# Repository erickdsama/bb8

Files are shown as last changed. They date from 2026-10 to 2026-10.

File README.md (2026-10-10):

# BB-8 con agente LLM

Un BB-8 de 30–35 cm que rueda, escucha y ve, manejado por Claude. Funciona como un
Sphero: una base de dos ruedas rueda por dentro de la esfera y un poste con imanes
sujeta la cabeza a través del casco. Claude nunca toca los motores: pide movimientos
acotados a un servidor MCP, el servicio de movimiento decide si obedece y el Arduino
frena solo si algo sale mal.

```
voz ─► Agente (Pi) ─► Claude ─► MCP bb8-motion ─► Servicio de movimiento ─► Arduino ─► motores, servo
                                     │                    ▲
                                     └─► Pi Zero (cabeza: cámara, ToF, ojo, voz)
                                          Mando Bluetooth ┘ (gana sobre el LLM)
```

**Toda la documentación está en la [wiki](wiki/Home.md).** Empieza por
[Arquitectura](wiki/Arquitectura.md) y luego sigue las partes en orden.

## El repo, parte por parte

El proyecto se construye en seis partes, en orden. Cada carpeta de `partes/` tiene
el código de esa parte y un README con qué hacer y cuándo está lista.

| Parte | Carpeta | Qué hay | Guía |
| --- | --- | --- | --- |
| 1 · Protoboard | [`partes/1-protoboard`](partes/1-protoboard) | Sketches de prueba `p1`…`p5` y el firmware completo del Arduino | [Parte 1](wiki/Parte-1-Protoboard.md) |
| 2 · Base de melamina | [`partes/2-base-melamina`](partes/2-base-melamina) | Montaje mecánico, sin código nuevo | [Parte 2](wiki/Parte-2-Base-de-melamina.md) |
| 3 · Base andando | [`partes/3-base-andando`](partes/3-base-andando) | Servicio de movimiento `bb8` (Pi) y `calibrar` | [Parte 3](wiki/Parte-3-Base-andando.md) |
| 4 · Agente controla el movimiento | [`partes/4-agente-movimiento`](partes/4-agente-movimiento) | Servidor MCP `bb8_mcp` y agente de voz `voz` | [Parte 4](wiki/Parte-4-Agente-controla-el-movimiento.md) |
| 5 · Agente controla la cabeza | [`partes/5-cabeza`](partes/5-cabeza) | Servidor de la cabeza `head` (Pi Zero 2 W) | [Parte 5](wiki/Parte-5-Agente-controla-la-cabeza.md) |
| 6 · Esfera y baterías | [`partes/6-esfera-baterias`](partes/6-esfera-baterias) | Gestor de energía `energia` (reposo y batería baja) | [Parte 6](wiki/Parte-6-Esfera-y-baterias.md) |

Además:

| Carpeta | Qué hay |
| --- | --- |
| [`cad/`](cad) | Piezas imprimibles en OpenSCAD paramétrico: esfera, base, poste y cabeza, con STL y renders |
| [`simulador/`](simulador) | Robot dummy: Arduino y cabeza simulados para correr todo en el PC sin hardware, y la prueba de punta a punta |
| [`sistema/`](sistema) | Servicios systemd, instaladores para la Pi y la Zero, ejemplo de `/etc/bb8.env` |
| [`docs/`](docs) | Documento técnico original y los artefactos (diagramas, avance, mecánica, animación) |
| [`wiki/`](wiki) | La wiki: guías por parte, arquitectura, protocolo, materiales, instalación |

## Pruébalo en tu PC en 2 minutos

Necesitas Python 3.11 o más nuevo. En Windows usa `py` en lugar de `python3`.

```bash
git clone https://github.com/erickdsama/bb8 && cd bb8
python3 -m venv .venv
source .venv/bin/activate              # Windows: .venv\Scripts\activate
pip install -r requirements.txt
pip install -e .                       # registra los paquetes de cada parte
python simulador/lanzar_dummy.py --camara sintetica
```

En otra terminal, con el venv activo: `python -m dummy.probar` recorre las ocho
herramientas MCP y los frenos de seguridad, y termina con `Todo bien`. Para hablarle
desde Claude Code: `claude mcp add --transport http bb8 http://127.0.0.1:8765/mcp`.
Dentro del repo, Claude Code ya lo encuentra por `.mcp.json`, y `CLAUDE.md` y `.claude/skills/` le explican el proyecto.
Detalles en [Simulador](wiki/Simulador.md) y [Conectar con Claude](wiki/Conectar-con-Claude.md).

## Por qué `pip install -e .`

El código de Python vive repartido en la carpeta de cada parte, pero los paquetes se
importan entre sí (`voz` usa `bb8.config`, el dummy usa `head`). `pyproject.toml`
mapea cada paquete a su carpeta, así que después de `pip install -e .` funcionan
`python -m bb8.motion_api`, `python -m bb8_mcp`, `python -m voz`, `python -m head.server`,
`python -m energia`, `python -m calibrar` y `python -m dummy.probar` desde cualquier
carpeta. `simulador/lanzar_dummy.py` funciona incluso sin ese paso.

## Estado

Partes 1–6 tienen código; el firmware compila para el Arduino Uno y todo se ha probado
contra el simulador, todavía no en el hardware real. Lo que falta está en
[Pendientes](wiki/Pendientes.md) y el avance en el
[tracker](docs/artefactos/avance-del-proyecto.html).

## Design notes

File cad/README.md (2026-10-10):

# CAD · piezas imprimibles del BB-8

Modelos paramétricos en OpenSCAD de todo lo que se imprime: la esfera en 14 gajos y 6
círculos, la base motriz, el poste con los imanes y la cabeza. Cambias un número en
`parametros.scad` y todo se recalcula (altura de las ruedas, de la plataforma, largo del
tubo, inclinación de los ball transfers…).

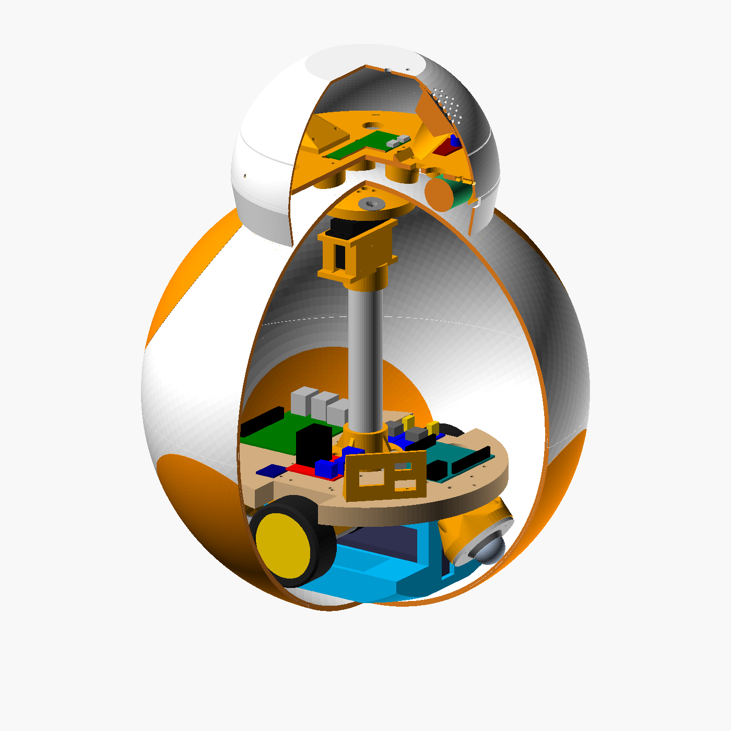
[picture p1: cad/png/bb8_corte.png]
BB-8 en corte


| Archivo | Qué tiene |
| --- | --- |
| `parametros.scad` | Todas las medidas. Las marcadas **MEDIR** vienen de hojas de vendedores que no coinciden: mide tu pieza antes de imprimir lo que depende de ellas |
| `componentes.scad` | Maquetas de lo comprado (JGB37, L298N, Uno, Pi 4, MG996R, Pi Zero, OV5647, anillo WS2812…). No se imprimen |
| `esfera.scad` | Casco: 14 gajos blancos, 6 círculos naranjas, tapa de carga, junta de bayoneta |
| `base.scad` | Plataforma (plantilla 1:1), soportes de motor, charola de LiPo con lastre, soportes de ball transfer, panel de carga |
| `poste.scad` | Pie del poste, soporte del servo, portaimanes |
| `cabeza.scad` | Casco de la cabeza, plato interior, soportes del ojo y de la bocina, tapones de las bolas |
| `ensamble.scad` | Todo junto, con corte y vista explotada |
| `exportar.sh` | Genera `stl/`, `plantillas/` y `png/` |

```bash
sudo apt install openscad xvfb      # o OpenSCAD desde openscad.org
bash cad/exportar.sh                # STL + plantilla + renders (~10 min, los gajos tardan)
bash cad/exportar.sh png            # solo los renders, segundos
openscad cad/ensamble.scad          # abrirlo y moverle
```

Los STL ya salen orientados para imprimir. Cuántas copias de cada uno, cómo imprimirlos,
la tornillería y las decisiones de diseño están en la wiki:
[Diseño 3D](../wiki/Diseno-3D.md).

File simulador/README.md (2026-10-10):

# Simulador

Robot dummy: imita al Arduino (TCP `:5555`) y a la cabeza (`:8080`) para correr el
servicio de movimiento, el MCP y el agente de voz en el PC, sin hardware.

```bash
pip install -r requirements.txt && pip install -e .     # desde la raíz del repo
python simulador/lanzar_dummy.py --camara sintetica
python -m dummy.probar                                  # en otra terminal: 19 comprobaciones
```

| Archivo | Hace |
| --- | --- |
| `lanzar_dummy.py` | Arranca dummy + `bb8.motion_api` + `bb8_mcp` |
| `dummy/world.py` | Habitación de 4 × 3 m con una silla y una caja |
| `dummy/arduino_sim.py` | Firmware simulado: protocolo, rampa, watchdog, frenos |
| `dummy/run_dummy.py` | Arduino y cabeza simulados |
| `dummy/visor.py` | Visor 2D en <http://127.0.0.1:8080/sim> |
| `dummy/probar.py` | Prueba de punta a punta por MCP |

Guía completa: [wiki/Simulador.md](../wiki/Simulador.md)

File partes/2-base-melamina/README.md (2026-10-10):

# Parte 2 · Base de melamina

Sin código nuevo: es el montaje mecánico de la base.

1. Disco de melamina 12–15 mm de Ø 20–22 cm con dos muescas para las ruedas.
2. Soportes de motor, ruedas de 65 mm con cople hexagonal de 6 mm.
3. 2 ball transfers de 1″ a 90° de las ruedas, a la misma altura de contacto.
4. Hueco de la LiPo (139 × 47 × 25 mm) centrado abajo; Arduino, L298N y buck arriba.
5. Poste central (PVC 25 mm o varilla 1/4″) con el portaimanes.
6. Repite `p2_motores_encoders` y `p4_mpu6050` de la [Parte 1](../1-protoboard): un cable flojo aparece ahí.

Piezas impresas (soportes de motor, charola con lastre, soportes de ball transfer) y la
plantilla 1:1 del disco: [`cad/`](../../cad).

**Lista cuando** se levanta con una mano y nada se mueve.

Guía completa: [wiki/Parte-2-Base-de-melamina.md](../../wiki/Parte-2-Base-de-melamina.md)

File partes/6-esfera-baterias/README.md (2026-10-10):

# Parte 6 · Esfera y baterías

El gestor de energía de la Pi principal: reposo ligero y profundo, y batería baja.

```
energia/__main__.py     máquina de estados activo → escuchando → ligero → profundo, API :8771
```

```bash
python -m energia --prueba    # tiempos cortos y sin apagar la Pi
python -m energia             # el profundo solo con BB8_REPOSO_PROFUNDO=1
```

Hardware de esta parte: LiPo 3S con fusible e interruptor, segundo buck para el
servo, Arduino alimentado por VIN, divisor de batería en A0 (`HAY_DIVISOR_BAT 1`) y
P-MOSFET de lado alto en A3 para cortar la Pi. La esfera impresa y la cabeza con
imanes también se arman aquí.

La esfera (14 gajos, 6 círculos, tapa de carga), el poste con imanes y la cabeza están
en [`cad/`](../../cad).

**Lista cuando** rueda sin cable, se duerme solo y despierta al moverlo.

Guía completa: [wiki/Parte-6-Esfera-y-baterias.md](../../wiki/Parte-6-Esfera-y-baterias.md)

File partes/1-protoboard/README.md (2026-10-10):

# Parte 1 · Componentes en protoboard

Todo lo que corre en el Arduino: cinco sketches de prueba para verificar cada
componente y el firmware completo del robot.

```
arduino/
├── pruebas/
│   ├── p1_i2c/                 ¿están vivos el MPU6050 (0x68) y el VL53L0X (0x29)?
│   ├── p2_motores_encoders/    cada motor en los dos sentidos; su encoder cuenta hacia arriba
│   ├── p3_servo/               barrido del MG996R en D9
│   ├── p4_mpu6050/             inclinación y rumbo
│   └── p5_vl53l0x/             distancia
└── bb8_firmware/               protocolo serial, PID con encoders, reflejos, reposo profundo
wokwi/                          el firmware en el simulador Wokwi (diagram.json, wokwi.toml)
```

1. Cablea según la tabla de pines de la guía (un L298N para los dos motores, jumpers ENA/ENB fuera, buck a 5.1 V en vacío).
2. Sube `p1`…`p5` en orden y abre el monitor serial a 115200 con "Nueva línea".
3. Instala la librería **VL53L0X de Pololu**, ajusta `CONFIGURACIÓN` arriba de `bb8_firmware.ino` y súbelo.
4. Desde la Pi o el PC: `python -m calibrar consola --serial /dev/ttyACM0` y prueba `I`, `?`, `M 80 80`.

Sin protoboard todavía: [wokwi/](wokwi/) corre el firmware en el simulador Wokwi con el
MPU6050, el servo, los encoders y LEDs en lugar de los motores.

**Lista cuando** `I` contesta `OK BB8 fw=0.1` y motores, servo, IMU y ToF responden.

Guía completa: [wiki/Parte-1-Protoboard.md](../../wiki/Parte-1-Protoboard.md) ·
Protocolo serial: [wiki/Protocolo.md](../../wiki/Protocolo.md)

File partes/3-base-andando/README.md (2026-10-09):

# Parte 3 · Base andando desde la Pi

El servicio de movimiento de la Pi principal y la herramienta de calibración.

```
bb8/                  paquete del servicio de movimiento
├── config.py         constantes a calibrar, límites y direcciones
├── protocol.py       líneas seriales (lo comparten la Pi y el dummy)
├── serial_link.py    una orden, una respuesta; /dev/ttyACM0 o socket://
├── motion.py         árbitro mando/LLM; move/turn con encoders y giroscopio
├── motion_api.py     API HTTP 127.0.0.1:8770
└── gamepad.py        mando Bluetooth con evdev (solo Linux)
calibrar/             consola, ticks, velocidad, rutina
```

Desde la raíz del repo, con el venv activo:

```bash
pip install -r requirements.txt evdev && pip install -e .
python -m calibrar ticks          # pulsos por vuelta (detén antes bb8.motion_api)
python -m calibrar velocidad      # ruedas en el aire
python -m bb8.motion_api --mando  # el servicio, con el mando Bluetooth
python -m calibrar rutina         # en el piso: avanza, gira 90°, vuelve
```

Copia los números a `bb8/config.py` y `PULSOS_MAX_CICLO` al firmware.

**Lista cuando** avanza, gira 90° y vuelve con deriva < 5°.

Guía completa: [wiki/Parte-3-Base-andando.md](../../wiki/Parte-3-Base-andando.md)

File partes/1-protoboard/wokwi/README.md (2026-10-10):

# Firmware en Wokwi

Simula el Arduino Uno con `bb8_firmware` en el navegador o en VS Code, antes de tener
el protoboard armado. Sirve para probar el protocolo serial y los reflejos a mano.

| Pieza real | En Wokwi | Pines |
| --- | --- | --- |
| L298N + 2 motores | 6 LEDs: `ENA`/`ENB` (brillo = PWM), `IN1`/`IN3` adelante, `IN2`/`IN4` atrás | D5 D7 D8 · D6 D11 D12 |
| Encoders de los motores | 2 perillas KY-040 (CLK = C1, DT = C2) | D2/D4 izq · D3/D10 der |
| MG996R del poste | `wokwi-servo` | D9 |
| MPU6050 | `wokwi-mpu6050` (con controles de aceleración y giro) | A4/A5, INT en A2 |
| Corte de la Pi | LED amarillo | A3 |
| Divisor de la batería | Potenciómetro (0–5 V ≈ 0–15.6 V) | A0 |
| VL53L0X | **no existe en Wokwi**: el firmware arranca sin él | — |

El anillo NeoPixel no está aquí: lo maneja la cabeza (Pi Zero), no el Arduino.

## En VS Code

1. Instala la extensión **Wokwi Simulator** (pide una licencia gratuita la primera vez).
2. Compila con los binarios exportados (los deja en `arduino/bb8_firmware/build/`, que git ignora):

   ```bash
   arduino-cli compile --fqbn arduino:avr:uno --export-binaries partes/1-protoboard/arduino/bb8_firmware
   ```

   O descarga el artefacto `firmware-uno` de la última corrida de CI y descomprímelo ahí.
3. Abre `partes/1-protoboard/wokwi/wokwi.toml` y ejecuta **Wokwi: Start Simulator**
   (si no lo encuentra, **Wokwi: Select Config File** y elige este `wokwi.toml`).

## En wokwi.com

Crea un proyecto nuevo de Arduino Uno y reemplaza sus archivos: pega
`bb8_firmware.ino` en `sketch.ino`, este `diagram.json` y este `libraries.txt`.

## Qué probar

Escribe en el monitor serial (115200, termina en salto de línea):

- `I` → `OK BB8 fw=0.1`, y `?` → la línea de estado. `F=` no debe incluir `imu`.
- `H 45` → el servo gira. `H -45` al otro lado.
- `M 120 120` → se encienden `ENA`, `ENB`, `IN1` e `IN3`, y se apagan solos a los 500 ms
  (watchdog: tecleando a mano no da tiempo de mandar otra `M`).
- Inclina el MPU6050 más de 35° (controles `accelX`/`accelY`) → `?` muestra `F=tilt` y `M` responde `ERR tilt`.
- `D 200` → hay un obstáculo a 20 cm durante 300 ms: `?` muestra `F=obstacle` y una `M` hacia
  adelante frena. Sustituye al ToF que Wokwi no tiene; como caduca rápido, pega `D 200` y `?` de una vez.
- Gira las perillas → los contadores `E=izq,der` de `?` cambian.

Ojo con el PID: los encoders no giran solos con los "motores", así que con `USAR_PID 1`
el lazo sube el PWM al máximo. Para ver el PWM directo pon `USAR_PID 0` en
`CONFIGURACIÓN`. Para probar la batería pon `HAY_DIVISOR_BAT 1` y baja el
potenciómetro: tras 5 s por debajo de ~3.2 V en A0 (9.9 V), `M` responde `ERR bateria`.

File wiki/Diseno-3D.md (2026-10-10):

# Diseño 3D

Todo lo que se imprime del BB-8, en OpenSCAD paramétrico: la esfera, la base motriz, el
poste con los imanes y la cabeza. Está en
[`cad/`](https://github.com/erickdsama/bb8/tree/main/cad); las medidas viven en
[`cad/parametros.scad`](https://github.com/erickdsama/bb8/blob/main/cad/parametros.scad)
y todo lo demás se calcula a partir de ellas.

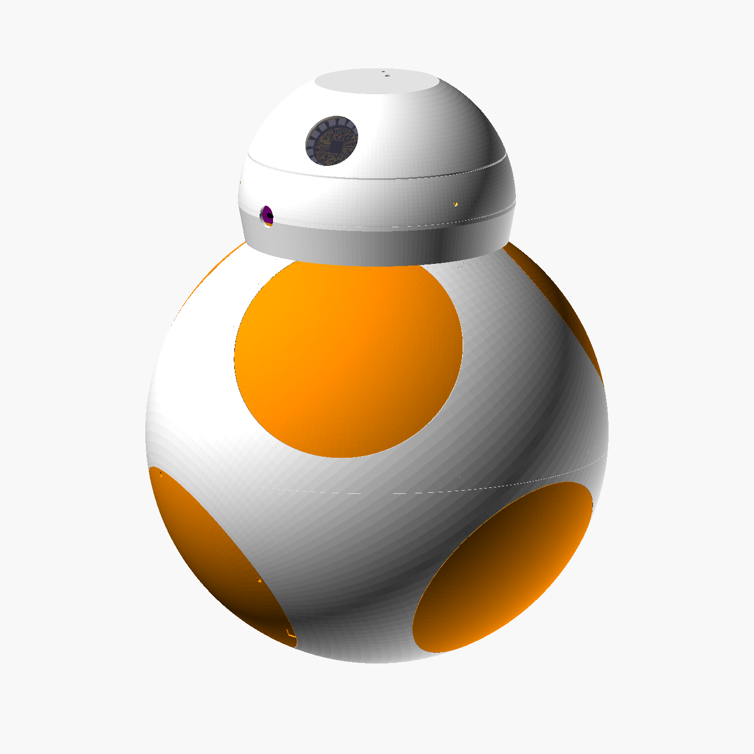
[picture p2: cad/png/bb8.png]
BB-8 completo

Corte

```bash
sudo apt install openscad xvfb
bash cad/exportar.sh          # STL en cad/stl, plantilla de la plataforma en cad/plantillas, renders en cad/png
bash cad/exportar.sh png      # solo renders
openscad cad/ensamble.scad    # el ensamble, con corte (corte=true) o explotado (explotar=1)
```

**Nada de esto se ha impreso todavía.** La geometría se revisó en el ensamble: nada de
la base, el poste ni la cabeza toca el casco salvo las ruedas y las bolas (intersección
CGAL vacía con 1 mm de margen). Antes de imprimir, mide lo marcado **MEDIR** en
`parametros.scad` (ver [Antes de imprimir](#antes-de-imprimir)).

## Cómo está pensado

Marco del robot: origen en el centro de la esfera, +z arriba, +y adelante, +x hacia la
rueda derecha. Esfera de 330 mm con pared de 4 mm (radio interior 161).

### Base

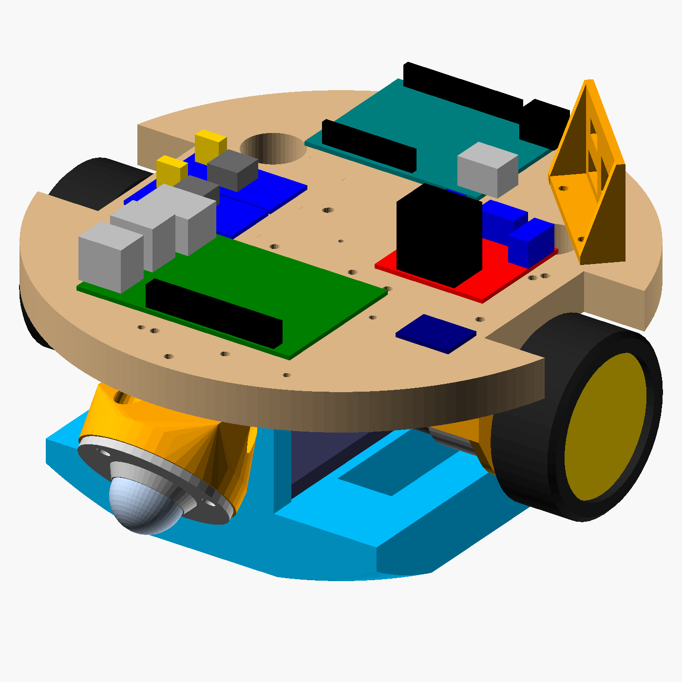
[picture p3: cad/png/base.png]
Base

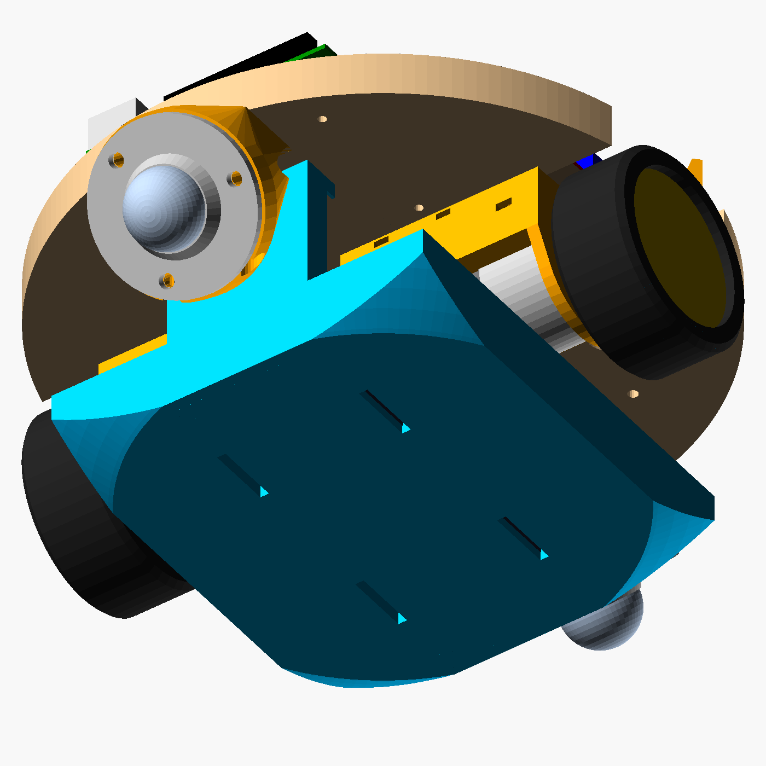
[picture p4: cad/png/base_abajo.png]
Base por abajo


- **Las ruedas salen de las piezas, no se eligen.** Los dos JGB37 van coaxiales y llenan el ancho: cople + caja de 22 mm + motor con encoder de 50 mm + 2 mm al centro ponen cada rueda a 94 mm del centro. Ahí la pared interior está inclinada 41°, así que la rueda (vertical) toca con el **borde exterior de la llanta**: fórrala con cinta de silicona y redondéale el canto. Inclinar los motores para que la llanta pise plana no cabe: el extremo del motor chocaría con el casco.
- **La plataforma va arriba y lo pesado cuelga.** El eje de las ruedas queda a z = −89.5 y la plataforma de melamina de 15 mm entre −68 y −53; a esa altura el casco deja 146 mm de radio libre, así que el disco de 210 mm entra holgado. Los motores cuelgan en soportes impresos con la placa frontal atornillada a la cara de la caja (M3 avellanados: la rueda pasa a 3 mm).
- **La LiPo va justo debajo de los motores** (z −134 a −109), en una charola colgada de la plataforma con dos paredes en los extremos. A cada lado de la LiPo, bajo los motores, hay un compartimento de lastre de 34 × 84 mm: caben ~0.5 kg de acero o ~0.75 kg de plomo por lado (la esfera recorta las esquinas), que es el lastre de 1–1.5 kg que pide la Parte 6, en el punto más bajo posible.
- **Ball transfers a ±110 mm en y**, fuera de la charola, inclinados 48° para que apunten al centro de la esfera. Sus soportes se nivelan con arandelas entre la brida y el soporte: las 4 patas (2 ruedas y 2 bolas) deben tocar el casco a la vez; si las bolas tocan primero, la esfera no rueda.
- **Plataforma:** `cad/plantillas/plataforma.svg` y `.dxf` a escala 1:1 con las muescas de las ruedas, todos los agujeros (soportes, charola, ball transfers, pie del poste, Pi 4, Uno, L298N, panel de carga) y dos pasacables de 22 mm. Imprímela en papel a 100 %, pégala en la melamina y taladra.
- Acomodo sobre la plataforma: Pi 4 adelante, Uno atrás, L298N a la izquierda, los dos LM2596 a la derecha, MPU6050 adelante a la izquierda con cinta doble cara (chip arriba) y el panel de carga atrás a la izquierda.

### Poste e imanes

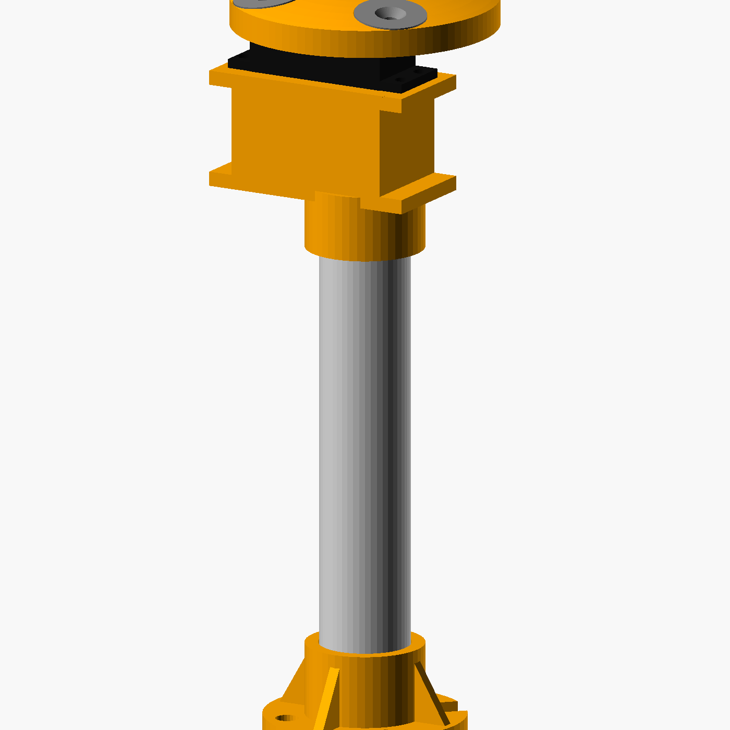
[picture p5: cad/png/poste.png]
Poste


Tubo PVC de 25 mm fijo en un pie impreso; arriba, el MG996R en un soporte que deja su eje
justo en el centro del tubo, y sobre el cuerno el portaimanes con 4 imanes N42 de 20 × 5 a
27 mm del eje. La cara de arriba del portaimanes es un casquete de la esfera interior
menos 2.5 mm: los imanes quedan a 2.5 mm del casco en toda su cara. `reportar()` en
`parametros.scad` da el largo exacto del tubo (con estas medidas, 150 mm: del fondo del pie
al tope dentro de la manga del soporte del servo). Recórtalo después de probar la base dentro de la
esfera, como pide la Parte 6.

### Cabeza

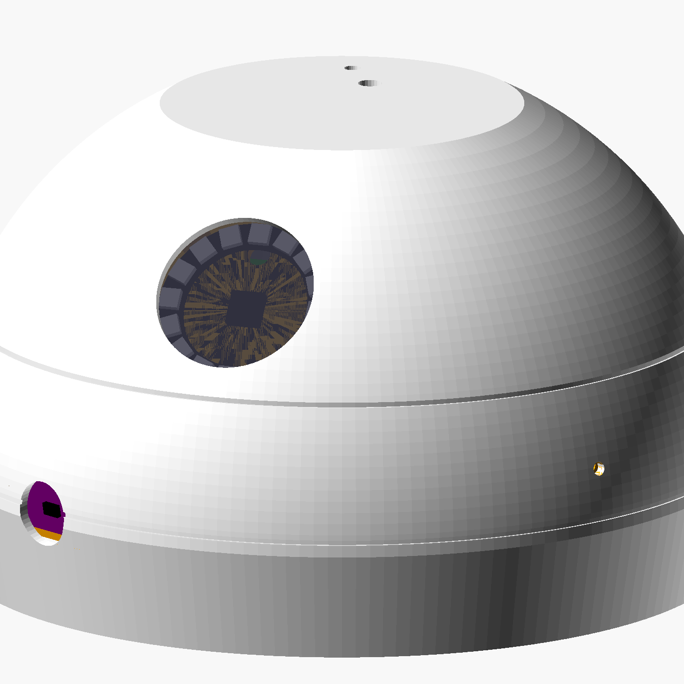
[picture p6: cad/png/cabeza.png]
Cabeza


- Ø 198 mm (0.6 de la esfera, la proporción del BB-8 de las películas), media esfera truncada arriba y una banda que baja siguiendo la curva del cuerpo a 4 mm.
- Se apoya en **3 bolas de acero de 1/2″** en copas a 60 mm del eje. Las ruedecitas del documento técnico solo ruedan en una dirección, y la esfera pasa debajo de la cabeza en todas. Las bolas entran por arriba y las retiene un tapón a presión (con grasa de litio o PTFE).
- 4 imanes en postes del plato, a 2 mm de la pintura: entre las caras de los imanes del poste y de la cabeza hay 8.5 mm (2.5 + 4 de pared + 2).
- Todo cuelga de un plato interior: el **power bank va debajo del plato**, atrás, para bajar el centro de gravedad; arriba van la Pi Zero 2 W (separadores M2.5), el PAM8403, el soporte del ojo y el de la bocina.
- **Ojo principal** a 38° de elevación: mica ahumada de 50 × 3 mm, el anillo WS2812 de 16 LED detrás y la OV5647 en un bolsillo del mismo soporte, con la lente en el centro del anillo.
- **Ojo chico** a 28° a la derecha: el VL53L0X, mirando 10° hacia abajo. Con su campo de 25°, el piso aparece hasta ~0.8 m, lejos de los 25 cm del freno.
- Bocina atrás y hacia arriba (45°) con rejilla hexagonal; dos agujeros de antena en la tapa; ranura del USB del power bank atrás, abajo.
- El casco baja sobre el plato y se fija con 3 tornillos M3 avellanados radiales a tuercas atrapadas en el plato.

### Esfera

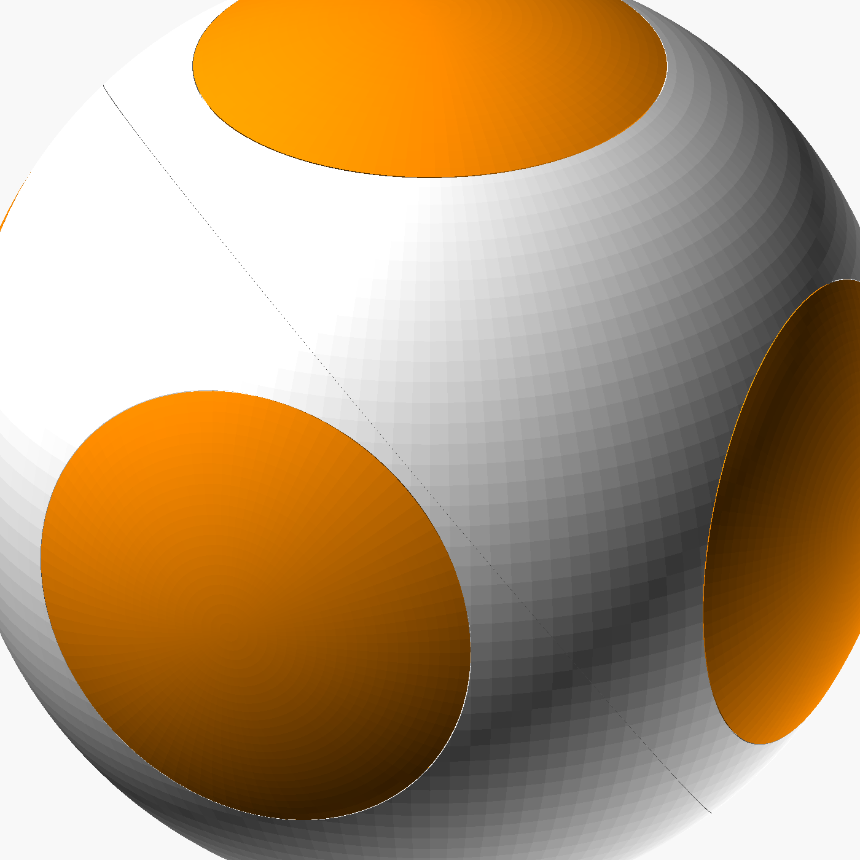
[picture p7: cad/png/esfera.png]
Esfera


- El patrón es el del BB-8: **6 círculos naranjas en las caras de un cubo** (30° de radio angular) y **8 gajos blancos**, uno por octante, como dice el documento técnico.
- **La junta de las dos mitades** es el gran círculo perpendicular a la diagonal (1,1,1) del cubo. Pasa entre los círculos a 5° de cada uno, así que ningún círculo queda partido; corta 6 gajos en dos, por eso son 14 piezas blancas.
- **Por dentro no sobresale nada**, porque ruedas y ball transfers pasan por todo el casco:
  - los círculos son tapas de 2 mm pegadas en un asiento de 2 mm (debajo queda un piso de 2 mm);
  - la junta es un traslape a media pared (10 mm) con **bayoneta de 6 lengüetas** de 0.6 mm que viven dentro de la pared: se encajan las mitades y se giran 7° para cerrar;
  - los gajos de una misma mitad se pegan a tope con espigas de filamento de 1.75 mm (18 agujeros), y luego se refuerzan por dentro con fibra de vidrio fina, lijada a ras.
- **Tapa de carga:** el círculo del eje −z del patrón tiene el piso abierto (queda una ceja de 8 mm) y se atornilla con 4 M2 × 4 avellanados. Para cargar, se gira la esfera con la mano (la base siempre cuelga) hasta ver el panel de carga por la tapa.

## Cambios respecto al documento técnico

| Documento técnico | Diseño 3D | Por qué |
| --- | --- | --- |
| XT60, JST-XH y rocker en un soporte detrás de la tapa (en el casco), con extensiones a la LiPo | Panel de carga en la **base** | La esfera gira alrededor de la base: un cable de la base al casco se enreda en la primera vuelta |
| Cabeza con 3 ruedecitas | 3 bolas de acero de 1/2″ en copas | Una rueda solo rueda en un sentido; la esfera pasa en todos |
| Cúpula de 12–14 cm | Cabeza de 198 mm (paramétrica) | El power bank mide 97 mm de largo y la proporción del BB-8 es ~0.6 del cuerpo. Cambia `cabeza_d` si prefieres otra |
| VL53L0X por I2C del Arduino | VL53L0X en la cabeza (ojo chico) | Dentro de la esfera solo vería el casco; en la cabeza lo lee la Zero (`/tof`) y el firmware va con `USAR_TOF_LOCAL 0` |
| Ball transfers "a la misma altura que las ruedas" | A ±110 mm, inclinados 48°, nivelados con arandelas | Es lo que hace que las 4 patas toquen la esfera a la vez |
| Base con LiPo "centrada abajo" | LiPo bajo los motores y lastre a sus lados en la charola | Es el punto más bajo que deja la geometría |

## Piezas a imprimir

PLA, boquilla 0.4. Los STL ya salen orientados. Cama mínima 220 × 220 × 170 mm (cada
gajo mide hasta 165 mm por lado).

| STL | Copias | Cómo |
| --- | --- | --- |
| `esfera_gajo_A_ppp` … `esfera_gajo_B_mmm` (14) | 1 de cada | 0.2 mm, 4 perímetros (pared maciza), soportes de árbol solo por dentro. El nombre dice la mitad (A/B) y el octante (p = +, m = −) |
| `esfera_circulo` | 5 | 0.2 mm, en naranja, cara convexa arriba, sin soportes |
| `esfera_tapa_carga` | 1 | Igual que los círculos |
| `base_soporte_motor`, `base_soporte_motor_izq` | 1 y 1 | 30 % de relleno, 4 perímetros |
| `base_charola` | 1 | 30 %; carga 450 g de LiPo + el lastre |
| `base_soporte_bt` | 2 | 40 %, soportes en el hueco del cuerpo |
| `base_panel_carga` | 1 | |
| `poste_pie_poste`, `poste_soporte_servo` | 1 y 1 | 30 % |
| `poste_portaimanes` | 1 | 50 %; los imanes N42 rompen piezas flojas |
| `cabeza_casco` | 1 | 0.2 mm, de pie, soportes de árbol por dentro (la tapa plana es un puente) |
| `cabeza_plato` | 1 | De cabeza (ya viene así), 30 % |
| `cabeza_soporte_ojo`, `cabeza_soporte_bocina` | 1 y 1 | Con soportes |
| `cabeza_tapon` | 3 | |

Tamaño y peso (sólido, PLA 1.24 g/cm³; es un tope, con relleno las piezas gruesas pesan menos):

| STL | Caja (mm) | cm³ | g |
| --- | --- | --- | --- |
| `base_charola.stl` | 132 × 148 × 69 | 208 | 258 |
| `base_panel_carga.stl` | 53 × 53 × 36 | 8 | 10 |
| `base_soporte_bt.stl` | 57 × 44 × 48 | 35 | 43 |
| `base_soporte_motor.stl` | 70 × 52 × 45 | 44 | 54 |
| `base_soporte_motor_izq.stl` | 70 × 52 × 45 | 44 | 54 |
| `cabeza_casco.stl` | 198 × 198 × 115 | 175 | 218 |
| `cabeza_plato.stl` | 189 × 189 × 31 | 153 | 189 |
| `cabeza_soporte_bocina.stl` | 48 × 58 × 65 | 6 | 8 |
| `cabeza_soporte_ojo.stl` | 52 × 61 × 56 | 28 | 35 |
| `cabeza_tapon.stl` | 13 × 13 × 8 | 1 | 1 |
| `esfera_circulo.stl` | 164 × 164 × 24 | 42 | 52 |
| `esfera_gajo_A_mmp.stl` | 125 × 125 × 57 | 28 | 35 |
| `esfera_gajo_A_mpm.stl` | 125 × 57 × 125 | 28 | 35 |
| `esfera_gajo_A_mpp.stl` | 140 × 163 × 163 | 112 | 138 |
| `esfera_gajo_A_pmm.stl` | 57 × 125 × 125 | 28 | 35 |
| `esfera_gajo_A_pmp.stl` | 163 × 140 × 163 | 112 | 138 |
| `esfera_gajo_A_ppm.stl` | 163 × 163 × 140 | 112 | 139 |
| `esfera_gajo_A_ppp.stl` | 163 × 163 × 163 | 133 | 165 |
| `esfera_gajo_B_mmm.stl` | 163 × 163 × 145 | 124 | 154 |
| `esfera_gajo_B_mmp.stl` | 163 × 163 × 133 | 104 | 129 |
| `esfera_gajo_B_mpm.stl` | 163 × 133 × 145 | 95 | 118 |
| `esfera_gajo_B_mpp.stl` | 49 × 115 × 115 | 21 | 26 |
| `esfera_gajo_B_pmm.stl` | 133 × 163 × 145 | 95 | 118 |
| `esfera_gajo_B_pmp.stl` | 115 × 49 × 115 | 21 | 26 |
| `esfera_gajo_B_ppm.stl` | 115 × 115 × 31 | 12 | 15 |
| `esfera_tapa_carga.stl` | 164 × 164 × 24 | 41 | 51 |
| `poste_pie_poste.stl` | 56 × 56 × 25 | 17 | 21 |
| `poste_portaimanes.stl` | 74 × 74 × 12 | 33 | 41 |
| `poste_soporte_servo.stl` | 61 × 33 × 48 | 30 | 37 |

Una copia de cada STL suma ~2.3 kg; con los 5 círculos y los 3 tapones, la esfera sola
ronda 1.6 kg de PLA, dentro de los 2–3 kg de filamento que pide la Parte 6.

## Tornillería y extras

Además del [pedido UNIT](Materiales.md):

| Pieza | Cant. | Para |
| --- | --- | --- |
| Tornillo M3 × 30 + tuerca | 18 | Soportes de motor (8), charola (4), ball transfers (6), a través de la melamina |
| Tornillo M3 × 6–8 avellanado | 6–12 | Cara de la caja de cada motor (los que coincidan de los 6) |
| Tornillo M3 × 25 + tuerca | 6 | Pie del poste (4), panel de carga (2) |
| Tornillo M4 × 16 + tuerca | 6 | Ball transfers |
| Tornillo M4 × 10 avellanado + tuerca de nylon | 8 | Imanes (ya en la lista de materiales) |
| Autorroscante M3 × 12 | 4 | Orejas del MG996R |
| Autorroscante M2 × 6 | 4 | Cuerno del servo al portaimanes |
| Autorroscante M2 × 4 avellanado | 4 | Tapa de carga |
| Tornillo M3 × 12 avellanado + tuerca | 3 | Casco de la cabeza al plato |
| Tornillo M3 × 10 + tuerca | 4 | Soportes del ojo y de la bocina |
| Separadores M2.5 de latón | 8 | Pi 4 (8 mm) y Pi Zero (5 mm) |
| Bola de acero 1/2″ (12.7 mm) | 3 | Cabeza |
| Mica acrílica ahumada Ø 50 × 3 mm | 1 | Ojo |
| Correa de velcro 20 mm | 2 | LiPo |
| Lastre (acero, plomo, perdigones con resina) | 1–1.5 kg | Charola |
| Tubo PVC conduit 25 mm | 20 cm | Poste |

**Imanes:** el poste los quiere con la **cara N avellanada** (avellanado arriba, N hacia el
casco) y la cabeza con la **cara S avellanada** (avellanado abajo). Pídelos así, o compra
8 iguales y comprueba con una brújula antes de atornillar: si la polaridad sale al revés,
la cabeza se repele.

## Antes de imprimir

Mide y corrige en `parametros.scad`:

- `caja_L` y `motor_L` del JGB37: la caja mide 19–29 mm según la reducción; el motor con encoder, ~50. Cambian la posición de las ruedas y todo lo de abajo.
- `rueda_offset`: distancia real de la cara de la caja al centro de la rueda con tu cople.
- Ball transfer: `bt_brida_d`, `bt_pcd`, `bt_cuerpo_d`, `bt_cuerpo_L`, `bt_bola_fuera`.
- MG996R: orejas (`servo_oreja_z`, `servo_agujeros`) y el cuerno (`cuerno_d`, y el radio de sus agujeros en `portaimanes`).
- `tubo_d`: el conduit de 25 mm mide 25; el hidráulico de 1/2″, 21.3.
- Cabeza: `anillo`, `tof`, `bocina_d` (la de UNIT puede ser de 40 o 50 mm), `powerbank`.
- Agujeros del L298N (`L298N_AG` en `base.scad`).

Luego imprime primero **dos gajos vecinos de mitades distintas** (por ejemplo `A_ppm` y
`B_pmm`) y prueba la bayoneta antes de gastar los 2 kg de filamento.

## Armado

1. Plataforma: corta y taladra con la plantilla. Monta motores, ruedas, charola y soportes de ball transfer; nivela con arandelas sobre una mesa (Parte 2).
2. Electrónica sobre la plataforma y prueba la base andando sin esfera (Partes 3 y 4).
3. Pega los 7 gajos de cada mitad con las espigas, refuerza por dentro y lija a ras.
4. Mete la base en la mitad B, cierra con la A y gira 7°. Prueba que rueda **antes** de poner lastre e imanes.
5. Corta el tubo, monta servo y portaimanes, pon el lastre y prueba que no vuelca al frenar.
6. Cabeza: plato con imanes, bolas y power bank; electrónica; casco con 3 tornillos.
7. Pinta: pega los círculos naranjas al final (la tapa de carga se atornilla).

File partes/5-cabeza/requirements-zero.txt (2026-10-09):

# Pi Zero 2 W (cabeza). Además: sudo apt install python3-picamera2 python3-opencv alsa-utils
# (crea el venv con --system-site-packages para ver picamera2 y opencv del sistema)
starlette>=0.37
uvicorn>=0.30
pillow>=10
adafruit-circuitpython-vl53l0x
adafruit-circuitpython-vl53l1x
adafruit-circuitpython-neopixel

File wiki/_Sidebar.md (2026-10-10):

**[Inicio](Home.md)**

**Entender**
- [Arquitectura](Arquitectura.md)
- [Protocolo](Protocolo.md)
- [Materiales](Materiales.md)

**Correr**
- [Simulador](Simulador.md)
- [Conectar con Claude](Conectar-con-Claude.md)
- [Instalación en la Pi](Instalacion-en-la-Pi.md)
- [Wake word "oye BB-8"](Wake-word-oye-BB-8.md)

**Construir**
- [1 · Protoboard](Parte-1-Protoboard.md)
- [2 · Base de melamina](Parte-2-Base-de-melamina.md)
- [3 · Base andando](Parte-3-Base-andando.md)
- [4 · Agente y movimiento](Parte-4-Agente-controla-el-movimiento.md)
- [5 · Cabeza](Parte-5-Agente-controla-la-cabeza.md)
- [6 · Esfera y baterías](Parte-6-Esfera-y-baterias.md)
- [Diseño 3D](Diseno-3D.md)

**Más**
- [Artefactos](Artefactos.md)
- [Pendientes](Pendientes.md)

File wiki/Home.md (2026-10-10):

# Wiki del BB-8

Un BB-8 de 30–35 cm que rueda, escucha y ve, manejado por Claude a través de un
servidor MCP. Esta wiki explica cómo está hecho y cómo correr cada pieza, del
protoboard a la esfera cerrada.

## Empieza aquí

1. [Arquitectura](Arquitectura.md): las tres capas (reflejos, servicio, agente), qué corre en cada placa y por qué Claude nunca toca los motores.
2. [Simulador](Simulador.md): corre todo en tu PC sin hardware y pruébalo de punta a punta.
3. [Conectar con Claude](Conectar-con-Claude.md): Claude Code, Claude Desktop o el agente de voz.

## Las seis partes, en orden

Cada parte termina con algo tangible. Nada de esfera hasta que la base ruede sola y
obedezca al agente; hasta la Parte 6 todo va con fuente de pared de 12 V.

| # | Parte | Corre en | Lista cuando |
| --- | --- | --- | --- |
| 1 | [Componentes en protoboard](Parte-1-Protoboard.md) | Arduino | Motores, servo, IMU y ToF responden; `I` contesta `OK BB8 fw=0.1` |
| 2 | [Base de melamina](Parte-2-Base-de-melamina.md) | — | Se levanta con una mano y nada se mueve |
| 3 | [Base andando desde la Pi](Parte-3-Base-andando.md) | Pi + Arduino | Avanza, gira 90° y vuelve con deriva < 5° |
| 4 | [Agente controla el movimiento](Parte-4-Agente-controla-el-movimiento.md) | Pi | "Oye Jarvis… ven acá" y se mueve |
| 5 | [Agente controla la cabeza](Parte-5-Agente-controla-la-cabeza.md) | Pi Zero + Pi | Gira la cabeza hacia ti y describe lo que ve |
| 6 | [Esfera y baterías](Parte-6-Esfera-y-baterias.md) | Pi + Arduino | Rueda sin cable, se duerme solo y despierta al moverlo |

## Referencia

- [Protocolo](Protocolo.md): serial Pi ↔ Arduino, HTTP del servicio de movimiento y de la cabeza, pinout.
- [Instalación en la Pi](Instalacion-en-la-Pi.md): servicios systemd, `/etc/bb8.env` y todas las variables `BB8_*`.
- [Wake word "oye BB-8"](Wake-word-oye-BB-8.md): entrenar el modelo propio en Colab y ponerlo en el robot.
- [Materiales](Materiales.md): lo que ya se compró (pedido UNIT 377466) y lo que falta.
- [Diseño 3D](Diseno-3D.md): esfera, base, poste y cabeza en OpenSCAD paramétrico, con STL listos para imprimir.
- [Artefactos](Artefactos.md): documento técnico, diagramas, tracker de avance, mecánica y animación.
- [Pendientes](Pendientes.md): lo que falta probar o construir.

## Mapa del repo

```
bb8/
├── partes/
│   ├── 1-protoboard/arduino/       pruebas p1…p5 + bb8_firmware
│   ├── 2-base-melamina/            montaje (sin código)
│   ├── 3-base-andando/             bb8/ (servicio de movimiento), calibrar/
│   ├── 4-agente-movimiento/        bb8_mcp/ (servidor MCP), voz/ (agente de voz)
│   ├── 5-cabeza/                   head/ (servidor de la Pi Zero)
│   └── 6-esfera-baterias/          energia/ (reposo y batería)
├── cad/                            piezas imprimibles en OpenSCAD (STL, plantilla, renders)
├── simulador/                      dummy/ + lanzar_dummy.py
├── sistema/                        systemd e instaladores
├── docs/                           documento técnico y artefactos HTML
├── wiki/                           esta wiki
├── pyproject.toml                  mapea cada paquete a su carpeta (pip install -e .)
└── requirements.txt                Pi principal y PC
```

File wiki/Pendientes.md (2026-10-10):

# Pendientes

## Probar en el hardware real

- El firmware compila para el Arduino Uno, pero solo se ha ejercitado su contraparte simulada.
- `head/backends_real.py` (cámara, ToF, NeoPixel, Piper en la Zero) no se ha corrido en la Zero.
- El agente de voz se probó contra el dummy con la API simulada, sin micrófono, Whisper ni Piper reales.
- Medir en la Pi 3 la RAM y la espera reales de Whisper `base` (hoy son estimados).

## Por construir

- Detección de obstáculos con la cámara a 5 fps en el servicio de movimiento (hoy frena el ToF).
- Entrenar el modelo "oye BB-8" en Colab (el pipeline está listo, ver [Wake word "oye BB-8"](Wake-word-oye-BB-8.md)); hasta entonces despierta con "hey Jarvis".
- Base de carga inductiva (opcional, después de la Parte 6).
- Identificación de voz sin torch (un modelo ONNX), para que quepa en la Pi 3 con Whisper local.

## Hardware confirmado

- Arduino Uno y Raspberry Pi 3 (1 GB) como Pi principal.
- La cámara OV5647 llega en otro pedido; mientras, la cabeza arranca sin ella.

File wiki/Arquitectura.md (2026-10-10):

# Arquitectura

BB-8 funciona como un Sphero: una base con dos ruedas rueda por dentro de la esfera
y la hace girar; el lastre abajo la mantiene derecha, y un poste con imanes sujeta la
cabeza a través del casco. El software no usa ROS: son tres capas, cada una más lenta
y más lista que la de abajo.

```mermaid
flowchart TD
  U[Tú, por voz] --> AG[Agente de voz<br/>Pi principal]
  AG -->|API| LLM[Claude<br/>tool use]
  LLM -->|herramientas MCP| MCP[Servidor MCP bb8-motion<br/>:8765/mcp]
  J[Mando Bluetooth<br/>gana sobre el LLM] --> MS[Servicio de movimiento<br/>127.0.0.1:8770]
  MCP --> MS
  MS -->|USB serial 115200| AR[Arduino<br/>firmware propio]
  AR --> M[2 motores + servo del poste]
  MCP <-->|WiFi :8080| Z[Pi Zero 2 W · cabeza<br/>cámara, ToF, ojo, altavoz]
  MS -->|GET /tof| Z
```

## Las tres capas

| Capa | Dónde | Ciclo | Hace |
| --- | --- | --- | --- |
| Reflejos | Arduino ([firmware](https://github.com/erickdsama/bb8/tree/main/partes/1-protoboard/arduino/bb8_firmware)) | 10 ms | Rampa, PID con encoders; frena si se inclina > 35°, si hay un obstáculo a < 25 cm o si pasan 500 ms sin órdenes |
| Servicio de movimiento | Pi, Python ([`bb8`](https://github.com/erickdsama/bb8/tree/main/partes/3-base-andando/bb8)) | 50 ms | Único dueño del serial. Convierte metros y grados en pulsos de encoder, arbitra entre mando y LLM, impone límites |
| Agente | Claude vía MCP ([`bb8_mcp`](https://github.com/erickdsama/bb8/tree/main/partes/4-agente-movimiento/bb8_mcp)) | 1–4 s | Decide qué herramienta sigue según lo que ve y oye |

Cada herramienta es corta y termina sola (máx. 2 m, 5 s, PWM 55 %), así que mientras
Claude piensa no hay un motor girando. Los límites viven en el servicio y en el
firmware, no en el prompt.

## Qué corre en cada placa

| Placa | Procesos | Código |
| --- | --- | --- |
| Raspberry Pi principal | `bb8.motion_api` (:8770), `bb8_mcp` (:8765), `voz`, `energia` (:8771) | partes 3, 4 y 6 |
| Raspberry Pi Zero 2 W (cabeza) | `head.server` (:8080): cámara OV5647, ToF, anillo WS2812, altavoz | parte 5 |
| Arduino Uno | `bb8_firmware`: L298N, encoders, servo MG996R, MPU6050, VL53L0X | parte 1 |
| Tu PC | El simulador reemplaza al Arduino y a la Zero; el resto es el mismo código | `simulador/` |

## Herramientas que ve Claude

| Herramienta | Qué hace |
| --- | --- |
| `move(metros)` | Avanza o retrocede hasta 2 m; devuelve `done`, `blocked` (obstáculo), `manual_override`, `cancelled` o `error` |
| `turn(grados)` | Gira sobre su eje con el giroscopio; + es derecha |
| `stop()` | Cancela cualquier movimiento |
| `look_at(grados)` | Gira la cabeza −90…90° con el servo del poste |
| `take_photo()` | Foto de la cabeza, 640 px |
| `set_eye_color(color, patron)` | Anillo NeoPixel |
| `say(texto o sonido)` | Habla con Piper (con balbuceo de pitidos antes) o pita |
| `express(emocion)` | Pitido de la emoción y el color de ojo que le toca (15 emociones, `head/personalidad.py`) |
| `get_pose()` | Posición, rumbo, inclinación, batería, distancia al frente |

## Seguridad

- El mando Bluetooth gana si se tocó en el último segundo.
- Voces no registradas pueden platicar, pero `move`, `turn` y `look_at` se bloquean en el código.
- El Arduino frena solo; Claude se entera después por el resultado `blocked`.
- El MCP escucha en 127.0.0.1 por defecto. Con `--host 0.0.0.0` no tiene contraseña: solo en la WiFi de casa.

Los mensajes exactos de cada enlace están en [Protocolo](Protocolo.md). Los diagramas
de cableado, alimentación y secuencia están en el artefacto
[Diagramas](Artefactos.md#diagramas).

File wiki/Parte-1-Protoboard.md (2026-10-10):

# Parte 1 · Componentes en protoboard

**Entregable:** los dos motores giran en ambos sentidos desde el Arduino con sus
encoders contando, el servo barre, la IMU y el ToF responden, y el firmware completo
contesta `OK BB8 fw=0.1`.

Código: [`partes/1-protoboard/arduino`](https://github.com/erickdsama/bb8/tree/main/partes/1-protoboard/arduino).

## Materiales

Arduino Uno, 1 L298N (el segundo queda de repuesto), 2 motorreductores
JGB37-520B 12 V 319 RPM con encoder, servo MG996R, MPU6050, VL53L0X, buck LM2596,
condensador 1000 µF 16 V, adaptador de 12 V 2 A con jack, protoboard + cables, Raspberry
Pi con su cargador. Todo viene en el [pedido UNIT 377466](Materiales.md).

## Cableado

| Pin Arduino | Va a | Uso |
| --- | --- | --- |
| D5 · D6 | L298N ENA · ENB | PWM izq · der (Timer0) |
| D7 · D8 | L298N IN1 · IN2 | Sentido motor izquierdo |
| D11 · D12 | L298N IN3 · IN4 | Sentido motor derecho |
| D2 · D4 | Encoder izq C1 · C2 | D2 = INT0 |
| D3 · D10 | Encoder der C1 · C2 | D3 = INT1 |
| D9 | Servo MG996R (naranja) | La librería Servo toma Timer1 |
| A4 · A5 | MPU6050 (0x68) + VL53L0X (0x29) | I2C SDA · SCL |
| A2 | MPU6050 INT | Despertar del reposo |
| A0 | Divisor de batería | Opcional, Parte 6 |
| A3 | MOSFET de la Pi | Parte 6, reposo profundo |
| USB | Raspberry Pi | Serial 115200 y 5 V |

- Adaptador 12 V → L298N (+12 V, GND) y → LM2596.
- LM2596 ajustado a **5.1 V sin nada conectado** → condensador 1000 µF (pata larga a +) → servo (rojo 5.1 V, café GND).
- En el L298N: quita los jumpers ENA y ENB, deja el jumper 5V-EN. No uses su salida de 5 V.
- Encoders: VCC 5 V y GND del Arduino.
- **Un solo riel de GND** para fuente, L298N, buck, servo y Arduino; la Pi llega por el USB.
- El Arduino come 5 V del USB de la Pi, así que una caída de los 12 V no lo reinicia.

Diagrama completo en el artefacto [Diagramas](Artefactos.md#diagramas), sección 1.

> Con el adaptador de 2 A no frenes una rueda con la mano mientras se mueve el servo:
> un motor trabado más el servo a tope pasan de 2 A.

## Sketches de prueba, en orden

Ábrelos en el Arduino IDE, sube, y abre el monitor serial a 115200 con "Nueva línea".
Ruedas en el aire la primera vez.

| Sketch | Qué prueba | Debe pasar |
| --- | --- | --- |
| `pruebas/p1_i2c` | Escáner I2C | Ve `0x68` (MPU6050) y `0x29` (VL53L0X) |
| `pruebas/p2_motores_encoders` | Cada motor en los dos sentidos. Teclas: `a`/`z` izq, `k`/`m` der, `b` ambos, espacio freno, `+`/`-` PWM, `r` reinicia contadores | "Adelante" hace avanzar al robot y su encoder cuenta **hacia arriba**. Si no, apunta qué invertir |
| `pruebas/p3_servo` | Barre −90…+90° y luego acepta un ángulo por el monitor (`30`, `-45`) | Llega a los extremos sin zumbar; servo alimentado del buck, nunca del pin 5V |
| `pruebas/p4_mpu6050` | Inclinación y rumbo | El rumbo sube al girar a la derecha; si baja, cambia `SIGNO_GIRO_Z` |
| `pruebas/p5_vl53l0x` | Distancia (librería VL53L0X de Pololu) | Sigue tu mano; alcance útil ~1.2 m en interiores, "fuera de rango" mirando al vacío es normal |

`p2_motores_encoders` también sirve para medir pulsos por vuelta: `r`, gira la rueda
10 vueltas a mano, divide `E` entre 10 y anótalo para `TICKS_PER_REV` (Parte 3).

## Firmware completo

`bb8_firmware/bb8_firmware.ino`. Instala la librería **VL53L0X de Pololu** desde el
Gestor de librerías y súbelo. Lo que se ajusta está arriba del archivo, en
`CONFIGURACIÓN`:

| Ajuste | Cuándo cambiarlo |
| --- | --- |
| `INVERTIR_MOTOR_IZQ` / `_DER`, `INVERTIR_ENC_IZQ` / `_DER` | Según lo que viste en `p2_motores_encoders` |
| `SIGNO_GIRO_Z` | Si `p4_mpu6050` baja el rumbo al girar a la derecha |
| `SERVO_INVERTIDO` | Si `H 40` gira la cabeza a la izquierda |
| `PULSOS_MAX_CICLO` | Con lo que diga `python -m calibrar velocidad` (Parte 3) |
| `USAR_TOF_LOCAL` | `0` cuando el ToF se mude a la cabeza (Parte 5) |
| `USAR_PID` | `0` si un encoder falla y quieres seguir probando en lazo abierto |
| `HAY_DIVISOR_BAT` | `1` con el divisor 10 kΩ / 4.7 kΩ de la batería en A0 (Parte 6) |

Con `arduino-cli`:

```bash
arduino-cli lib install VL53L0X
arduino-cli compile --fqbn arduino:avr:uno partes/1-protoboard/arduino/bb8_firmware
arduino-cli upload -p /dev/ttyACM0 --fqbn arduino:avr:uno partes/1-protoboard/arduino/bb8_firmware
```

El robot tiene que estar **quieto el primer segundo** mientras calibra el giroscopio.
Si `?` responde `F=imu`, el MPU6050 no contestó al arrancar.

## Probar el firmware en Wokwi

Antes de cablear, el firmware corre en el simulador [Wokwi](https://wokwi.com) con el
MPU6050, el servo, dos encoders KY-040 y LEDs en lugar del L298N. El VL53L0X no existe
en Wokwi; el obstáculo se simula con la orden `D`. Instrucciones y qué probar en
[`partes/1-protoboard/wokwi/`](https://github.com/erickdsama/bb8/blob/main/partes/1-protoboard/wokwi/README.md).

El CI compila el firmware para el Arduino Uno en cada push; el `.hex` queda como
artefacto `firmware-uno` de la corrida.

## Probar el firmware a mano

Desde la Pi o el PC, con el repo instalado (`pip install -e .`):

```bash
python -m calibrar consola --serial /dev/ttyACM0
```

Escribe órdenes del [protocolo](Protocolo.md): `I`, `?`, `M 80 80`, `H 40`, `S`.
Sin órdenes `M` durante 500 ms, el watchdog frena solo.

## Lista cuando

- [ ] `p1`…`p5` pasan
- [ ] `I` contesta `OK BB8 fw=0.1` y `?` no muestra `F=imu`
- [ ] `M 80 80` mueve las dos ruedas hacia adelante y se detienen solas a los 500 ms
- [ ] Foto del cableado tomada (sirve en la Parte 2 para no perder conexiones)

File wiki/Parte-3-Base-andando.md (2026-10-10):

# Parte 3 · Base andando desde la Pi

**Entregable:** la base se maneja por órdenes desde la Pi por USB, con el mando
Bluetooth y con una rutina automática: avanza, gira 90°, vuelve y frena en el piso sin
la esfera. Video de 30 s.

Código: [`partes/3-base-andando`](https://github.com/erickdsama/bb8/tree/main/partes/3-base-andando).

| Archivo | Hace |
| --- | --- |
| `bb8/config.py` | Constantes a calibrar, límites de seguridad y direcciones |
| `bb8/protocol.py` | Arma y lee las líneas seriales (lo comparten la Pi y el dummy) |
| `bb8/serial_link.py` | Una orden, una respuesta; abre `/dev/ttyACM0` o `socket://` |
| `bb8/motion.py` | Servicio de movimiento: árbitro mando/LLM, `move`/`turn` con encoders y giroscopio |
| `bb8/motion_api.py` | API HTTP local en `127.0.0.1:8770` |
| `bb8/gamepad.py` | Mando Bluetooth con `evdev` (solo Linux) |
| `calibrar/` | Consola serial, pulsos por vuelta, velocidad máxima y rutina de prueba |

## Preparar la Pi

Raspberry Pi 3 con Raspberry Pi OS Lite de 64 bits, Arduino Uno por USB con el firmware de la Parte 1.

```bash
git clone https://github.com/erickdsama/bb8 && cd bb8
python3 -m venv .venv && source .venv/bin/activate
pip install -r requirements.txt evdev
pip install -e .
```

Empareja el mando con `bluetoothctl` (`scan on`, `pair`, `trust`, `connect`). Tu usuario
necesita los grupos `dialout` (serial) e `input` (mando).

## Calibrar

Con el puerto serial directo (detén antes `bb8.motion_api`, que es el único dueño del
serial):

```bash
python -m calibrar ticks        # gira la rueda 10 vueltas a mano → pulsos por vuelta
python -m calibrar velocidad    # ruedas en el aire → velocidad máxima y PWM mínimo
python -m calibrar consola      # órdenes a mano: M 80 80, ?, S, H 30…
```

`--serial` cambia el puerto (por defecto `BB8_SERIAL` o `/dev/ttyACM0`).

Copia los números a [`bb8/config.py`](https://github.com/erickdsama/bb8/blob/main/partes/3-base-andando/bb8/config.py)
y `PULSOS_MAX_CICLO` al firmware:

| Constante | Cómo medirla |
| --- | --- |
| `TICKS_PER_REV` | Girar la rueda 10 vueltas a mano, leer `E` con `?`, dividir entre 10 (de fábrica 1320) |
| `SLIP_FACTOR` | Mandar `move(1.0)`, medir con cinta; `SLIP_FACTOR = metros_ordenados / metros_reales` |
| `TRACK_WIDTH_M` | Distancia entre centros de las ruedas (de fábrica 0.17) |
| `V_MAX_MPS` | Velocidad a PWM 255 con la fuente de 12 V (~0.9 m/s con el L298N) |
| `PWM_CRUISE`, `PWM_MIN` | Subir hasta que cabecee y bajar un 20 %; mínimo con el que arranca desde parado |
| `PULSOS_MAX_CICLO` (firmware) | Lo que diga `calibrar velocidad` |

## Manejarla

```bash
python -m bb8.motion_api --mando      # /dev/ttyACM0, cabeza en bb8-head.local
```

El mando manda si se tocó en el último segundo (`MANUAL_HOLD_S`), con PWM máximo 150.
Desde otra terminal puedes probar la API:

```bash
curl -X POST localhost:8770/move -d '{"metros": 0.5}'
curl -X POST localhost:8770/turn -d '{"grados": 90}'
curl localhost:8770/pose
```

Rutas completas en [Protocolo § 2](Protocolo.md#2-http-del-servicio-de-movimiento-pi-1270018770).

## Rutina de prueba

Con el servicio corriendo, base en el piso y 1 m libre al frente:

```bash
python -m calibrar rutina    # avanza, gira 90°, vuelve; mide la deriva con la IMU
```

Para que arranque solo al encender: servicio `bb8-motion` en
[Instalación en la Pi](Instalacion-en-la-Pi.md).

## Lista cuando

- [ ] `calibrar ticks` y `velocidad` hechos; números copiados a `config.py` y al firmware
- [ ] El mando la conduce y suelta el control al segundo de no tocarlo
- [ ] `calibrar rutina` vuelve con deriva < 5°
- [ ] Frena sola ante una caja a 25 cm y al inclinarla más de 35°
- [ ] Video de 30 s

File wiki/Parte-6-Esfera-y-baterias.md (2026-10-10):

# Parte 6 · Esfera y baterías

**Entregable:** esfera de 30–35 cm en dos mitades que cierran sin cinta, con la base
rodando adentro y la cabeza flotando encima. El BB-8 completo, sin cable, que se
duerme solo y despierta al moverlo.

Código: [`partes/6-esfera-baterias`](https://github.com/erickdsama/bb8/tree/main/partes/6-esfera-baterias)
(gestor de energía `energia`).

## Alimentación con la LiPo

LiPo 3S 11.1 V 5.2 Ah (XT60) → fusible 5 A → interruptor rocker → L298N, buck de la Pi
y buck del servo. La cabeza sigue con su power bank.

- **Segundo buck para el servo.** Un LM2596 da ~2 A reales; la Pi 3 pide hasta ~1.2 A con Whisper en los 4 núcleos y un MG996R trabado 2.5 A. Usa uno para la Pi (con el condensador de 1000 µF, a 5.1 V) y otro solo para el servo.
- **El Arduino come por VIN desde la batería** (después del interruptor), no solo por el USB de la Pi, para seguir vivo cuando corta la Pi.
- Nunca bajar de 3.3 V por celda (~10 V); la alarma de voltaje (en el pedido) se pone a 3.5 V.
- Divisor 10 kΩ / 4.7 kΩ de la batería a **A0** y `HAY_DIVISOR_BAT 1` en el firmware: así `?` reporta `V=` y el firmware rechaza `M` por debajo de 9.9 V.
- Carga: el XT60 hembra, la extensión de balanceo JST-XH y el rocker van en un panel **en la base** (no en el casco: la esfera gira alrededor de la base y el cable se enredaría). Se alcanzan por la tapa de carga, uno de los círculos naranjas, girando la esfera con la mano. Rocker apagado, iMAX B6AC en modo Balance a 2.6 A (~2 h). La batería nunca sale del robot.

Diagrama "banco contra LiPo" en el artefacto [Diagramas](Artefactos.md#diagramas), sección 2.

## Reposo

```bash
python -m energia            # reposo ligero; el profundo solo con BB8_REPOSO_PROFUNDO=1
python -m energia --prueba   # tiempos cortos (10 s / 20 s / 40 s) y sin apagar la Pi
```

```
activo ──30 s sin actividad──▶ escuchando ──5 min──▶ ligero ──30 min o "a dormir"──▶ profundo
cualquier actividad (wake word, orden MCP, mando, alguien lo mueve) ──▶ activo
```

- **Ligero:** `Z` al Arduino (servo sin PWM, motores libres), cámara pausada y ojo tenue.
- **Profundo:** `P <s>` al Arduino y apagado de la Pi; el Arduino corta la Pi y la vuelve a encender cuando la IMU nota movimiento (~25 s de arranque).
- **Batería:** aviso a 10.5 V; a 10.0 V se duerme (profundo, o ligero si no hay MOSFET).
- API en `127.0.0.1:8771`: `POST /actividad`, `POST /dormir`, `GET /estado`.

### Corte de la Pi para el reposo profundo

El corte va en **A3** con un **P-MOSFET de lado alto** de nivel lógico (p. ej. AO3401 o
un módulo "high-side") y pull-down de 100 kΩ en la compuerta: A3 en alto apaga la Pi, y
un reset del Arduino (pasa cada vez que la Pi abre el puerto) la deja encendida. El
módulo IRF520 del documento técnico corta la tierra y **no sirve** aquí: la Pi y el
Arduino comparten tierra por el USB.

Con el MOSFET instalado: `BB8_REPOSO_PROFUNDO=1` en `/etc/bb8.env` y
`sudo systemctl enable --now bb8-energia`. El instalador ya da permiso al usuario `bb8`
para `systemctl poweroff`.

## Esfera

El modelo ya está hecho: [Diseño 3D](Diseno-3D.md#esfera) tiene los 14 gajos, los 6
círculos, la tapa de carga y la bayoneta de la junta, en OpenSCAD paramétrico y en STL.

1. Imprime los gajos de [`cad/stl`](https://github.com/erickdsama/bb8/tree/main/cad/stl) (6 círculos naranjas + 14 piezas blancas que forman los 8 gajos), con espigas de filamento de 1.75 mm.
2. Imprime con capa de 0.28 mm y 10–15 % de relleno (~2–3 kg de PLA).
3. Pega, **refuerza por dentro** (fibra de vidrio o segunda capa de resina), lija, primer, pinta y laca.
4. Prueba que la base rueda dentro de la esfera **antes** de poner imanes y lastre; si las ruedas giran pero la esfera no, los ball transfers tocan primero.
5. Recorta el poste para que los imanes queden a 2–3 mm de la pared.
6. Lastre hasta 1–1.5 kg en total, lo más abajo posible; prueba que la base no vuelque al frenar.
7. Cabeza: cúpula impresa con 3 bolas de acero de 1/2″ para que los imanes no rocen la pintura (unas ruedecitas solo ruedan en un sentido). Imanes N42 20 × 5 mm: 4 en el poste cara N arriba, 4 en la cabeza cara S abajo.

Los N42 de 20 mm lastiman dedos y rompen piezas impresas: sepáralos con una cuña de
madera, nunca deslizando.

Ver el artefacto [Mecánica](Artefactos.md#mecánica) y [Materiales](Materiales.md) para
lo que falta comprar (batería, cargador, imanes, filamento).

## Lista cuando

- [ ] LiPo cargada en modo Balance, 12.6 V con celdas parejas
- [ ] `?` reporta el voltaje real (`HAY_DIVISOR_BAT 1`)
- [ ] La esfera rueda con la base adentro y la cabeza no se cae al frenar
- [ ] Se duerme solo y despierta al moverlo

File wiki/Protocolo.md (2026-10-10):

# Protocolo de comunicación del BB-8

Versión 0.2 · 2026-10-09 (añade `P`, banderas `bateria` e `imu`, `ERR bateria`). Fuente única de verdad para el firmware del Arduino, el
código de la Pi, la cabeza (Pi Zero 2 W) y el robot dummy. Si algo cambia aquí,
cambia en [`partes/3-base-andando/bb8/protocol.py`](https://github.com/erickdsama/bb8/blob/main/partes/3-base-andando/bb8/protocol.py),
en [`simulador/dummy/arduino_sim.py`](https://github.com/erickdsama/bb8/blob/main/simulador/dummy/arduino_sim.py)
y en el firmware [`partes/1-protoboard/arduino/bb8_firmware`](https://github.com/erickdsama/bb8/tree/main/partes/1-protoboard/arduino/bb8_firmware).

## Quién habla con quién

```mermaid
flowchart LR
  CL[Claude<br/>Desktop, Code o agente de voz] -->|MCP streamable-http :8765<br/>o stdio| MCP[bb8-motion<br/>servidor MCP]
  MCP -->|HTTP JSON :8770<br/>solo localhost| MS[Servicio de movimiento]
  PAD[Mando BT<br/>evdev] --> MS
  MS -->|serial USB 115200<br/>líneas ASCII| AR[Arduino]
  MCP -->|HTTP WiFi :8080<br/>foto, ojo, hablar| Z[Pi Zero 2 W<br/>cabeza]
  MS -->|HTTP WiFi :8080<br/>GET /tof cada 100 ms| Z
  MS -.->|D &lt;mm&gt; reenvía el ToF| AR
```

| Enlace | Transporte | Dirección | Quién inicia |
| --- | --- | --- | --- |
| Claude → MCP | MCP streamable-http (`/mcp`, puerto 8765) o stdio | petición/respuesta | Claude |
| MCP → servicio de movimiento | HTTP JSON, `127.0.0.1:8770` | petición/respuesta | MCP, agente de voz |
| Servicio → Arduino | Serial USB 115200 8N1, una línea por orden | petición/respuesta, una a la vez | Siempre la Pi |
| MCP → cabeza | HTTP JSON, `bb8-head.local:8080` | petición/respuesta | MCP |
| Servicio → cabeza | HTTP `GET /tof` cada 100 ms | sondeo | Servicio |

Reglas que no se rompen:

- El servicio de movimiento es el **único** proceso que abre el puerto serial.
- El Arduino nunca habla sin que le pregunten: toda línea suya es la respuesta a una línea de la Pi.
- El MCP no habla con el Arduino; todo movimiento pasa por el servicio (árbitro mando/LLM).
- En el dummy, el puerto serial es `socket://127.0.0.1:5555` (pyserial lo abre igual que `/dev/ttyACM0`) y la cabeza es `http://127.0.0.1:8080`.

## 1. Serial Pi → Arduino

115200 baudios, 8N1, ASCII. Cada orden es una línea terminada en `\n` (se acepta
`\r\n`), máximo 63 caracteres, tokens separados por un espacio. El Arduino
responde **exactamente una línea** por orden: `OK [datos]` o `ERR <motivo>`.
La Pi espera la respuesta (timeout 200 ms) antes de mandar la siguiente.

| Orden | Argumentos | Respuesta OK | Qué hace |
| --- | --- | --- | --- |
| `M <izq> <der>` | enteros −255…255 | `OK` | Velocidad objetivo de cada rueda en escala PWM. El PID por encoders y la rampa (máx. 30 por ciclo de 10 ms) la persiguen. Alimenta el watchdog. |
| `S` | — | `OK` | Alto inmediato con freno, sin rampa. Siempre se acepta, aun dormido. |
| `H <grados>` | entero −90…90 | `OK` | Ángulo del poste (cabeza). 0 = al frente, + derecha. Con MG996R posicional: servo = 90 + grados. |
| `D <mm>` | entero 0…4000 | `OK` | Última distancia del ToF de la cabeza, reenviada por la Pi. 0 = sin lectura. Válida 300 ms. |
| `?` | — | `OK V=… T=… Y=… E=…,… H=… D=… F=…` | Estado (ver abajo). |
| `Z` | — | `OK` | Dormir: freno, motores sin PWM, servo `detach()`, rechaza `M` y `H`. |
| `W` | — | `OK` | Despertar: `attach()` del servo y vuelve a la última posición despacio. |
| `I` | — | `OK BB8 fw=<versión>` | Identificación. El dummy responde `fw=sim-0.1`. |
| `P <s>` | entero 0, 5…120 | `OK` | Reposo profundo (Parte 6): frena y, pasados `s` segundos, corta la alimentación de la Pi (A3), duerme y despierta cuando la IMU detecta movimiento; entonces reconecta la Pi. La Pi lo manda justo antes de `shutdown -h`. `P 0` cancela una cuenta pendiente. |

### Línea de estado `?`

```
OK V=11.62 T=3.1 Y=-12.4 E=1420,1398 H=0 D=1830 F=-
```

| Clave | Unidad | Significado |
| --- | --- | --- |
| `V` | voltios | Batería. `0.00` = no se mide (sin divisor en A0, fuente de pared hasta la Parte 6) |
| `T` | grados | Inclinación absoluta (máx. de pitch y roll) del MPU6050 |
| `Y` | grados | Rumbo integrado del giroscopio, + derecha, sin envolver (puede pasar de 360) |
| `E` | pulsos | Encoders izquierdo,derecho acumulados con signo desde el arranque |
| `H` | grados | Ángulo actual del poste |
| `D` | mm | Última distancia ToF recibida con `D` (0 si caducó) |
| `F` | lista | Banderas activas separadas por coma, o `-`: `obstacle`, `tilt`, `watchdog`, `sleep`, `bateria` (menos de 10.5 V durante 5 s), `imu` (el MPU6050 no responde: sin freno por inclinación ni rumbo) |

La Pi debe ignorar claves que no conozca, para poder añadir campos sin romper nada.

### Errores

| Respuesta | Cuándo |
| --- | --- |
| `ERR syntax` | Orden desconocida, argumentos que faltan o no son enteros |
| `ERR range` | Argumento fuera de rango |
| `ERR obstacle` | `M` con avance neto (`izq + der > 0`) mientras `D` < 250 mm. Retroceder y girar en el sitio sí se aceptan |
| `ERR tilt` | `M` mientras la inclinación supera 35°. Se libera sola por debajo de 25° |
| `ERR sleep` | `M` o `H` estando dormido |
| `ERR bateria` | `M` con la batería por debajo de 9.9 V (3.3 V por celda). Solo con el divisor en A0 |

### Reflejos del firmware (no esperan a la Pi)

| Evento | Reacción | Bandera |
| --- | --- | --- |
| Inclinación > 35° | Freno inmediato, objetivo a 0 | `tilt` |
| `D` válido < 250 mm y avanzando | Freno inmediato, objetivo a 0 | `obstacle` |
| Ruedas con objetivo ≠ 0 y 500 ms sin un `M` | Freno, objetivo a 0 | `watchdog` (se borra con el siguiente `M`) |

Solo `M` alimenta el watchdog: si el lazo de movimiento de la Pi se cuelga, el `?`
del sondeo no mantiene vivos los motores. Por eso el servicio reenvía `M` cada
100 ms mientras hay movimiento.

### Arranque

Abrir el puerto reinicia el Uno (~2 s). La Pi espera 2 s, vacía la entrada,
manda `I` y comprueba que la respuesta empiece por `OK BB8`.

### Ejemplo de sesión

```
Pi  → I            Ard → OK BB8 fw=0.1
Pi  → H 0          Ard → OK
Pi  → D 1830       Ard → OK
Pi  → M 70 70      Ard → OK
Pi  → ?            Ard → OK V=12.00 T=1.2 Y=0.3 E=310,305 H=0 D=1610 F=-
Pi  → D 240        Ard → OK          (el Arduino frena solo aquí)
Pi  → M 70 70      Ard → ERR obstacle
Pi  → M -60 -60    Ard → OK          (retroceder sí se permite)
Pi  → S            Ard → OK
```

### Nota sobre el ToF

El ToF vive en la cabeza, pero el freno reflejo vive en el Arduino. El servicio de
movimiento lee `GET /tof` de la Zero cada 100 ms y lo reenvía como `D <mm>`.
Solo lo reenvía si la cabeza mira al frente (`|H| ≤ 15°`); si mira a un lado manda
`D 0`, porque esa distancia no es la del camino. Si la WiFi se cae, `D` caduca a
los 300 ms y el freno por ToF deja de actuar; el watchdog y la IMU siguen.

### Cambio por el L298N

El documento técnico asumía DRV8871 (2 pines PWM por motor). Con el L298N cada
motor usa 1 PWM (`EN`) + 2 de dirección (`IN`). El protocolo no cambia; solo el
firmware. Pinout acordado con el hilo de diagramas (Arduino Uno, un L298N para los
dos motores, jumpers ENA/ENB quitados):

| Pin | Función |
| --- | --- |
| D5 / D6 | ENA / ENB (PWM, Timer0), motor izq / der |
| D7, D8 | IN1, IN2 (motor izquierdo) |
| D11, D12 | IN3, IN4 (motor derecho) |
| D2 / D3 | Encoder C1 izq / der (INT0 / INT1) |
| D4 / D10 | Encoder C2 izq / der |
| D9 | Servo del poste (la librería Servo inutiliza el PWM de D9 y D10) |
| A4 / A5 | I2C: MPU6050 (0x68) y, en las Partes 1–4, VL53L0X (0x29) |
| A2 | INT del MPU6050 (pin-change, para despertar) |
| A3 | Corte de la Pi para el reposo profundo (Parte 6). En alto = Pi apagada, así un reset del Arduino la deja encendida |
| A0 | Divisor de voltaje de batería (campo `V` de `?`) |

**ToF local en las Partes 1–4.** Mientras el ToF esté en el bus I2C del Arduino,
el firmware usa esa lectura para el freno y `D` es opcional (si llegan las dos,
gana la local). Cuando el sensor pase a la cabeza, la Pi empieza a mandar `D`.

El L298N tira ~2 V, así que a 12 V el motor ve ~10 V: velocidad máxima ~0.9 m/s
en vez de 1.08 m/s. No tiene modo sleep; en `Z` el firmware pone `EN` a 0.

## 2. HTTP del servicio de movimiento (Pi, `127.0.0.1:8770`)

JSON en ambos sentidos. Solo escucha en localhost: lo usan el MCP y el agente de voz.

| Método y ruta | Cuerpo | Respuesta |
| --- | --- | --- |
| `POST /move` | `{"metros": 1.0}` (−2…2) | resultado de movimiento |
| `POST /turn` | `{"grados": 90}` (−360…360, + derecha) | resultado de movimiento |
| `POST /look_at` | `{"grados": 30}` (−90…90) | `{"resultado":"done","grados":30}` |
| `POST /stop` | — | `{"resultado":"done"}`. Cancela lo que esté en curso |
| `GET /pose` | — | pose (abajo) |
| `POST /manual` | `{"izq": 120, "der": 120}` | Lo usa el mando. Reenviar cada ≤ 200 ms o el watchdog para |
| `POST /sleep`, `POST /wake` | — | `{"resultado":"done"}` |
| `POST /apagar` | `{"segundos": 15}` (5…120) | `{"resultado":"done","corte_en_s":15}`. Manda `P`; quien llama hace `shutdown -h` enseguida |

Resultado de movimiento:

```json
{"resultado": "done", "metros": 0.98, "segundos": 2.1}
{"resultado": "blocked", "metros": 0.42, "distancia_m": 0.24, "motivo": "obstacle"}
{"resultado": "manual_override"}
{"resultado": "cancelled", "metros": 0.3}
{"resultado": "timeout", "metros": 1.7}
{"resultado": "error", "motivo": "tilt"}
```

`resultado` es uno de `done`, `blocked`, `manual_override`, `cancelled`, `timeout`,
`error`. Las órdenes de movimiento van en cola: una a la vez; `stop` se salta la cola.
El mando tiene prioridad: si mandó algo en el último segundo, `move`, `turn` y
`look_at` devuelven `manual_override` sin moverse.

Pose:

```json
{"x_m": 0.52, "y_m": -0.10, "rumbo_deg": 12.4, "inclinacion_deg": 1.2,
 "bateria_v": 11.62, "cabeza_deg": 0, "tof_m": 1.83, "banderas": [],
 "control": "llm", "dormido": false, "arduino": "OK BB8 fw=0.1"}
```

`control` es `llm`, `manual` (mando activo en el último segundo) o `idle`.

## 3. HTTP de la cabeza (Pi Zero 2 W, puerto 8080)

| Método y ruta | Cuerpo / parámetros | Respuesta |
| --- | --- | --- |
| `GET /estado` | — | `{"ok":true,"camara":"picamera2"\|"webcam"\|"sintetica"\|"ninguna","tof":"vl53l0x"\|"vl53l1x"\|"ninguno"\|"sim"}` |
| `GET /foto` | `?ancho=640` | `image/jpeg`, lado mayor = `ancho`. 503 `{"ok":false,"error":…}` si la cabeza no tiene cámara |
| `GET /tof` | — | `{"mm": 1830, "t": 1760000000.12}`; `mm = 0` sin lectura |
| `POST /ojo` | `{"color":"#3080ff" o "azul","patron":"fijo"\|"respirar"\|"parpadeo"\|"apagado","brillo":0.3}` | `{"ok":true}` |
| `POST /hablar` | `{"texto":"hola"}` o `{"sonido":"feliz"\|"triste"\|"alerta"\|"pregunta"}` | `{"ok":true,"segundos":1.2}` al terminar |
| `GET /cara` | — | `{"ok":true,"caras":[{"x":0.21,"y":-0.1,"area":0.034}]}`, de mayor a menor; `x` −1…1 de izquierda a derecha de la foto. 501 sin OpenCV, 503 sin cámara |
| `POST /reposo` | `{"activo": false}` | Reposo ligero: cámara pausada y ojo con respiración azul al 3 %. `{"activo": true}` lo revierte |

Colores con nombre aceptados: `rojo, verde, azul, blanco, naranja, amarillo,
morado, cian, apagado`. El brillo se limita a 0.3 (el anillo pide ~1 A a blanco pleno).

Solo en el dummy:

| Ruta | Para qué |
| --- | --- |
| `POST /sim/empujar` | `{"grados": 40}` simula que alguien lo inclina durante 1 s |
| `GET /sim/mundo` | Estado real del robot simulado: pose, cabeza, PWM, banderas, rayo del ToF, ojo y última frase |
| `GET /sim` | Visor 2D en el navegador |

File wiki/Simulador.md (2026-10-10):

# Simulador (robot dummy)

El simulador reemplaza los dos extremos del robot, el Arduino y la cabeza, y deja
todo lo demás igual: el servicio de movimiento, el servidor MCP y el agente de voz son
exactamente el código que corre en la Pi. Sirve para probar a Claude manejando el
robot antes de tener hardware.

Código: [`simulador/`](https://github.com/erickdsama/bb8/tree/main/simulador).

| Archivo | Hace |
| --- | --- |
| `dummy/world.py` | Habitación de 4 × 3 m con una silla y una caja |
| `dummy/arduino_sim.py` | Firmware simulado por TCP `:5555`: mismo protocolo, rampa, watchdog, frenos por ToF e inclinación |
| `dummy/run_dummy.py` | Arranca el Arduino y la cabeza simulados |
| `dummy/visor.py`, `dummy/visor.html` | Visor 2D en el navegador (`/sim`) |
| `dummy/probar.py` | Prueba de punta a punta por MCP |
| `lanzar_dummy.py` | Arranca dummy + servicio de movimiento + MCP con un solo comando |

## Instalar

Python 3.11 o más nuevo. En Windows usa `py` en lugar de `python3`.

```bash
git clone https://github.com/erickdsama/bb8 && cd bb8
python3 -m venv .venv
source .venv/bin/activate          # Windows: .venv\Scripts\activate
pip install -r requirements.txt
pip install -e .
```

## Correr

```bash
python simulador/lanzar_dummy.py                    # webcam 0 como cámara de la cabeza
python simulador/lanzar_dummy.py --camara sintetica # Claude ve la habitación simulada
python simulador/lanzar_dummy.py --camara 1         # otra webcam
python simulador/lanzar_dummy.py --camara ninguna   # cabeza sin cámara (take_photo falla, lo demás no)
python simulador/lanzar_dummy.py --sin-sonido       # sin pitidos en el PC
```

Cuando aparece `✅ BB-8 dummy listo`, corren tres procesos:

| Proceso | Dirección | Hace de |
| --- | --- | --- |
| `dummy.run_dummy` | serial `socket://127.0.0.1:5555`, cabeza `http://127.0.0.1:8080` | Arduino y Pi Zero |
| `bb8.motion_api` | `http://127.0.0.1:8770` | Servicio de movimiento (igual que en la Pi) |
| `bb8_mcp` | `http://127.0.0.1:8765/mcp` | Servidor MCP (igual que en la Pi) |

Con `--camara sintetica` Claude ve paredes, una silla café a 1.6 m al frente y una
caja verde: útil para probar "mira, esquiva y sigue". Con la webcam ve tu cuarto real
aunque el robot se mueva por la habitación simulada.

## Ver al robot moverse

Con el dummy corriendo, abre <http://127.0.0.1:8080/sim> en el navegador. Es una
vista desde arriba de la habitación que se actualiza 10 veces por segundo mientras
Claude (o `dummy.probar`) maneja el robot por el MCP:

- El robot a escala, con una flecha hacia donde avanza y el ojo dibujado del lado
  hacia donde mira la cabeza, en su color y con su patrón (fijo, respirar, parpadeo).
- El rayo del ToF punteado hasta lo que toca; se pone rojo por debajo de 25 cm, la
  distancia a la que el Arduino frena solo.
- La estela del camino recorrido y un globo con lo último que dijo.
- Al lado: pose, rumbo, ángulo de la cabeza, inclinación, distancia del ToF, PWM de
  cada motor (actual → objetivo), frenos activos (obstáculo, inclinación, watchdog,
  dormido, chocando) y la cámara de la cabeza una vez por segundo.
- Botones para pausar la cámara, borrar la estela y "empujar 40°" (frena por
  inclinación, como en la prueba).

El visor solo mira: no manda órdenes de movimiento. Lee
`GET /sim/mundo`, que también sirve para scripts:

```bash
curl http://127.0.0.1:8080/sim/mundo
```

Se sirve desde el mismo proceso de la cabeza simulada, así que no hay que instalar
nada más ni abrir otro puerto.

## Probar que todo funciona

Con el dummy corriendo con `--camara sintetica`, en otra terminal con el venv activo:

```bash
python -m dummy.probar
```

Recorre las ocho herramientas, choca a propósito contra la silla (debe frenar solo a
~21 cm), comprueba que el mando gane al LLM, que `stop` cancele y que una inclinación
de 40° frene. Guarda la foto en `foto_dummy.jpg` y termina con `Todo bien`
(19 comprobaciones).

## Calibración contra el dummy

`calibrar` también habla con el Arduino simulado, útil para practicar la Parte 3:

```bash
python -m calibrar consola --serial socket://127.0.0.1:5555
```

Detén antes el servicio de movimiento, que es el único dueño del serial (en el dummy,
corre `python -m dummy.run_dummy` solo).

## Problemas comunes

| Síntoma | Causa |
| --- | --- |
| `No arrancó http://127.0.0.1:8080/estado` | Otro proceso usa el puerto 8080, 5555, 8770 u 8765 |
| `ModuleNotFoundError: bb8` al usar `python -m` | Falta `pip install -e .` en el venv activo |
| `ImportError: FastMCP` | Tienes `mcp` 2.x; `requirements.txt` fija `mcp>=1.10,<2` |
| `/cara` falla | `opencv-python` 5.x quitó los detectores Haar; se fija `<5` |

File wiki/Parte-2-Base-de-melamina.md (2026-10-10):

# Parte 2 · Base de melamina

**Entregable:** un disco de melamina de 20–22 cm con motores, ruedas, apoyos y
electrónica fijos, con el hueco de la batería listo. Se levanta con una mano y nada
se mueve.

No hay código nuevo. La carpeta [`partes/2-base-melamina`](https://github.com/erickdsama/bb8/tree/main/partes/2-base-melamina)
solo tiene esta lista.

## Materiales

| Pieza | Nota |
| --- | --- |
| Melamina 12–15 mm, 30 × 30 cm | 3 mm de MDF se pandea con 1.5 kg encima |
| 2 ruedas de goma 65 mm con **cople hexagonal para eje D de 6 mm** | La "Llanta de Goma 65 mm" de UNIT **con accesorios** sí entra (buje hex 12 mm); la de motor TT es otra. Forrarlas con cinta de silicona. Ver [Materiales](Materiales.md) |
| 2 soportes de motor JGB37 | |
| 2 ball transfers de 1″, bola metálica | Resbalan mejor sobre el casco que una rueda loca |
| Tubo PVC 25 mm × 30 cm o varilla roscada 1/4″ + 4 tuercas | Poste central |
| Separadores M3 de latón, tornillos M3, cinta doble cara, velcro, bridas | Los separadores y tornillos vienen en el pedido UNIT |

Ninguno, salvo la tornillería, está todavía en el [pedido](Materiales.md).

## Piezas impresas y plantilla

El [Diseño 3D](Diseno-3D.md#base) tiene la plantilla 1:1 del disco con todos los
agujeros (`cad/plantillas/plataforma.svg`), los soportes de motor colgantes, la charola
de la LiPo con compartimentos de lastre y los soportes inclinados de los ball transfers.
Con ellos la plataforma queda arriba y lo pesado cuelga debajo; los pasos de abajo
siguen valiendo si prefieres armarla a mano.

## Pasos

1. Corta el disco de Ø 20–22 cm; marca el centro y los ejes en + y ×.
2. Haz dos muescas opuestas para las ruedas y atornilla los soportes de motor de modo que las ruedas asomen por ellas.
3. Monta los 2 ball transfers a 90° de las ruedas, **a la misma altura de contacto** que las ruedas. Si tocan antes, la esfera no rodará.
4. Deja el hueco de la LiPo (139 × 47 × 25 mm) centrado **abajo**: hace de lastre. Arduino, L298N y buck van arriba, sobre separadores M3.
5. Fija el poste central (PVC o varilla roscada) con el portaimanes arriba. Se recorta en la Parte 6.
6. Recablea lo de la [Parte 1](Parte-1-Protoboard.md) con cables cortos y termorretráctil; mantén un solo riel de GND.
7. Pesa el conjunto y anota el centro de gravedad: tiene que quedar lo más abajo posible.

## Comprobar

Repite dos pruebas de la Parte 1 después de montar: un cable flojo aparece ahí.

- `p2_motores_encoders`: cada rueda en los dos sentidos y su encoder cuenta.
- `p4_mpu6050`: la IMU quedó bien orientada (chip arriba) y el rumbo sube al girar a la derecha.

Mira también el artefacto [Mecánica](Artefactos.md#mecánica) para ver cómo se acomoda
todo dentro de la esfera.

## Lista cuando

- [ ] La base se levanta con una mano y nada se mueve ni cuelga
- [ ] Las ruedas y los ball transfers tocan una superficie plana al mismo tiempo
- [ ] `p2` y `p4` pasan otra vez
- [ ] Peso y centro de gravedad anotados

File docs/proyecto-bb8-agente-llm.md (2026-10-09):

# Proyecto BB-8 con agente LLM

Sep 19, 2026 · @Erick

## 1. Arquitectura

Un BB-8 de 30–35 cm con el principio del Sphero: una base con dos ruedas rueda por dentro de la esfera y un poste con imanes sujeta la cabeza a través del casco. El movimiento lo escribe un servicio propio, sin ROS, y se expone al LLM como servidor MCP. El mando Bluetooth usa el mismo servicio para pruebas y tiene prioridad cuando lo tocas.

```mermaid
flowchart TD
  U[Usuario<br/>voz] --> AG[Agente de voz<br/>Pi principal]
  AG -->|API| LLM[Claude<br/>tool use]
  LLM -->|tools| MCP[Servidor MCP<br/>bb8-motion]
  J[Mando BT<br/>pruebas, prioridad] --> MS[Servicio de movimiento<br/>Python]
  MCP --> MS
  MS -->|serial USB| AR[Arduino<br/>firmware propio]
  AR --> M[2 motores + servo del poste]
  MCP <-->|WiFi| Z[Pi Zero 2 W<br/>cámara, ToF, ojo, altavoz]
```

| Pieza | Rol |
| --- | --- |
| Raspberry Pi (normal) | Servicio de movimiento, servidor MCP, agente de voz |
| Arduino | Firmware de motores, encoders, servo, IMU; reflejos de seguridad |
| Raspberry Pi Zero 2 W | Cabeza: cámara, sensor ToF, NeoPixel, altavoz; batería propia |
| Mando Bluetooth | Control manual para pruebas, prioridad sobre el LLM |
| Claude | Decide qué hacer a partir de voz y fotos; nunca toca motores |

## 2. Plan por partes

Seis partes en orden de dependencia; cada una termina con algo tangible. Nada de esfera hasta que la base ruede sola y obedezca al agente. Las baterías entran hasta la Parte 6: antes, la Pi va con su cargador USB y los motores con una fuente de pared de 12 V.

### Parte 1 — Componentes conectados en protoboard

*Entregable:* los dos motores giran en ambos sentidos desde el Arduino, el servo barre 0–180° y la IMU imprime ángulos en el monitor serial.

- [ ] Ajustar el buck a 5.1 V en vacío antes de conectar nada
- [ ] Cablear en protoboard: fuente 12 V → DRV8871 ×2; Pi con su cargador USB; GND común entre fuente, Pi y Arduino
- [ ] Firmware mínimo: protocolo serial `M <izq> <der>` y `H <ángulo>`, respuesta `OK`/`ERR`
- [ ] Probar motores con PWM al 50 % y freno; probar servo; leer MPU6050 por I2C
- [ ] Foto del cableado y tabla de pines (va a la sección Electrónica)

### Parte 2 — Todo montado en la base de melamina

*Entregable:* un disco de melamina de 20–22 cm con motores, ruedas, ball transfers y electrónica fijos, con el hueco de la batería listo; se levanta con una mano y nada se mueve.

- [ ] Cortar el disco, marcar centro y ejes en + y ×
- [ ] Atornillar soportes de motor con las ruedas asomando por dos muescas opuestas
- [ ] Montar 2 ball transfers a 90° de las ruedas, a la misma altura de contacto
- [ ] Dejar el hueco de la LiPo (139 × 47 × 25 mm) centrado abajo; Arduino, drivers y buck arriba
- [ ] Poste central (tubo PVC 25 mm o varilla roscada) con el portaimanes arriba
- [ ] Pesar el conjunto y anotar el centro de gravedad

### Parte 3 — Test de movimiento con la base

*Entregable:* la base se maneja por comandos desde la Pi por USB y avanza, gira y frena en el piso sin la esfera; video de 30 s.

- [ ] Pi principal con Raspberry Pi OS Lite, conectada al Arduino por USB
- [ ] Servicio de movimiento en la Pi: envía `M`/`H`/`S`, lee la IMU, watchdog de 500 ms
- [ ] Mando Bluetooth con `evdev` para conducirla a mano
- [ ] Rutina de prueba: adelante 1 s, giro 90°, alto; medir deriva con la IMU
- [ ] Ajustar PWM máximo y rampa de aceleración para que no cabecee

### Parte 4 — Agente LLM controlando el movimiento

*Entregable:* le dices "BB-8, ven acá" o "da una vuelta" y la base lo hace; log de la conversación con las llamadas a herramientas.

- [ ] Servidor MCP `bb8-motion` con `move`, `turn`, `stop`, `get_pose` sobre el servicio de la Parte 3
- [ ] Probarlo primero desde Claude Desktop o Claude Code con el robot en el piso
- [ ] Micrófono y altavoz USB en la Pi; openWakeWord → faster-whisper `small` → Claude con tool use → Piper
- [ ] Personalidad en el system prompt; pitidos de droide entre respuestas
- [ ] Registro de voces (ver Voz e identificación)

### Parte 5 — Agente LLM controlando la cabeza

*Entregable:* la cabeza (todavía sin carcasa) gira hacia quien habla, la cámara manda una foto al modelo y BB-8 describe lo que ve; el ojo NeoPixel cambia de color según el estado.

- [ ] Chasis de cabeza: cámara OV5647, ToF VL53L1X, NeoPixel, power bank 18650, PAM8403 + altavoz
- [ ] Modificar el MG996R del poste a rotación continua si la cabeza va a girar 360°
- [ ] Herramientas MCP `look_at`, `take_photo`, `set_eye_color`, `say`
- [ ] Foto reducida a 640 px antes de enviarla al modelo
- [ ] Probar la unión magnética cabeza–poste sobre una superficie curva (una pelota de playa sirve)

### Parte 6 — Esfera impresa en 3D y baterías

*Entregable:* esfera de 30–35 cm en dos mitades que cierran sin cinta, con la base rodando adentro y la cabeza flotando encima; el BB-8 completo y sin cable.

- [ ] Modelar en Fusion 360: 6 círculos naranjas + 8 piezas blancas, cortadas para la cama de la impresora, con biscós de alineación
- [ ] Imprimir con 0.28 mm de capa y 10–15 % de relleno; \~2–3 kg de filamento
- [ ] Pegar, reforzar por dentro (fibra de vidrio o segunda capa de resina), lijar, primer, pintar, laca
- [ ] Cargar la LiPo con el B6AC en modo Balance; verificar 12.6 V y celdas parejas
- [ ] Pasar de la fuente de pared a LiPo → interruptor + fusible → drivers y buck; fijar la LiPo centrada abajo con velcro y brida
- [ ] Cortar el poste a la medida para que los imanes queden a 2–3 mm de la pared
- [ ] Lastre hasta 1–1.5 kg total, lo más abajo posible; probar que la base no vuelque al frenar
- [ ] Cabeza: cúpula impresa con 3 ruedecitas para que los imanes no rocen la pintura

## 3. Materiales

Qué tener en la mesa antes de empezar cada parte. ☑ = ya comprado. Precios aproximados en MXN a octubre de 2026; el total ronda los $5,600–7,700. Las partes 1 y 2 se pueden pedir juntas; la 5 y la 6 conviene esperar a que la 3 ruede, por si cambia el tamaño de la esfera.

| ✓ | Parte | Pieza | Cant. | Tienda | MXN |
| --- | --- | --- | --- | --- | --- |
| ☑ | 1 | Motorreductor JGB37-520B con encoder, 12 V, 319 RPM | 2 | UNIT | 231 c/u |
| ☑ | 1 | IMU MPU6050 | 1 | UNIT | 87 |
| ☑ | 1 | Servo MG996R | 2 | UNIT | 114 c/u |
| ☑ | 1 | Buck LM2596 ajustable 3 A | 1 | UNIT | 42 |
| ☑ | 1 | Condensador 1000 µF 16 V | 4 | UNIT | 3 c/u |
| ☑ | 1 | Kit protoboard + cables Dupont | 1 | UNIT | 200 |
| ☐ | 1 | Driver DRV8871 | 2–3 | Amazon | 119 c/u |
| ☐ | 1 | Fuente de pared 12 V 3 A con jack barril | 1 | Steren | 150 |
| ☐ | 1 | Adaptador jack barril a terminales de tornillo | 1 | Steren / UNIT | 30 |
| ☐ | 1 | Cable calibre 18 rojo/negro | 2 m | Steren | 60 |
| ☐ | 2 | Melamina 12–15 mm, 30 × 30 cm | 1 | Maderería | 80 |
| ☐ | 2 | Rueda de goma 65 mm + cople hexagonal eje D 6 mm | 2 | Mercado Libre | 75 c/u |
| ☐ | 2 | Soporte de motor JGB37 | 2 | Mercado Libre | 40 c/u |
| ☐ | 2 | Ball transfer 1″ | 2 | Mercado Libre | 60 c/u |
| ☐ | 2 | Tubo PVC 25 mm × 30 cm o varilla roscada 1/4″ + 4 tuercas | 1 | Ferretería | 40 |
| ☐ | 2 | Cinta doble cara 3M VHB | 1 | Mercado Libre | 100 |
| ☐ | 2 | Velcro adhesivo, bridas, tornillos M3 y pijas | 1 kit | Ferretería | 100 |
| ☐ | 2 | Termorretráctil surtido | 1 | Steren | 60 |
| ☐ | 3 | microSD 32 GB + cable USB a Arduino | 1 | Ya los tienes | 0 |
| ☐ | 3 | Mando Bluetooth (PS4/Xbox/genérico) | 1 | Ya lo tienes | 0 |
| ☐ | 4 | Micrófono USB (o ReSpeaker 2-Mic HAT, \~$450) | 1 | Steren / Amazon | 250 |
| ☐ | 4 | Bocina USB o DAC USB para la Pi principal | 1 | Steren | 150 |
| ☑ | 4 | Módulo Bluetooth HC-05 (opcional) | 1 | UNIT | 91 |
| ☐ | 5 | Raspberry Pi Zero 2 W + microSD | 1 | Ya la tienes | 0 |
| ☑ | 5 | Cámara OV5647 5 MP + cable de 15 pines para Zero | 1 | UNIT | 240 |
| ☑ | 5 | Anillo NeoPixel 16 LED WS2812, 45 mm | 1 | UNIT | 34 |
| ☐ | 5 | Sensor ToF VL53L1X | 1 | UNIT | 80 |
| ☐ | 5 | Power bank 18650 tipo tubo, 2,600 mAh | 1 | Mercado Libre | 250 |
| ☐ | 5 | Amplificador PAM8403 (o MAX98357 I2S) | 1 | Amazon / Geek Factory | 40–155 |
| ☐ | 5 | Altavoz 3 W 4 Ω | 1 | Geek Factory | 60 |
| ☐ | 5 | Cúpula 12–14 cm (impresa o media esfera de plástico) | 1 | Mercado Libre | 150 |
| ☐ | 5 | Imanes neodimio N42 20 × 5 mm | 8 | Mercado Libre | 150 |
| ☐ | 5 | 3 ruedecitas + eje 2.5 mm | 1 | Mercado Libre | 60 |
| ☐ | 6 | LiPo 3S 11.1 V 5200 mAh 80C, conector XT60 | 1 | Amazon / Geek Factory | 700–900 |
| ☐ | 6 | Cargador balanceador iMAX B6AC 80 W | 1 | UNIT / Amazon | 350–700 |
| ☐ | 6 | Alarma de voltaje LiPo 1S–8S | 1 | UNIT | 60 |
| ☐ | 6 | Conector XT60 macho con cable + XT60 hembra de panel | 1 | UNIT / Amazon | 80 |
| ☐ | 6 | Conector JST-XH 4 pines de panel + divisor en Y | 1 | Amazon | 60 |
| ☐ | 6 | Interruptor rocker 10 A | 1 | Steren | 40 |
| ☐ | 6 | Portafusible + fusibles 5 A | 1 | Steren | 50 |
| ☐ | 6 | Filamento PLA 1.75 mm | 2–3 kg | Mercado Libre | 600–900 |
| ☐ | 6 | Gorilla gel, resanador, primer, pintura blanca/naranja/plata, laca, lijas, cinta de pintor | 1 | Tlapalería | 300–500 |
| ☐ | 6 | Lastre (pesas o plomo) | 200–400 g | Mercado Libre | 50 |
| ☐ | 6 | Tuercas de nylon para imanes | 8 | Ferretería | 20 |
| ☐ | 6 | Módulo MOSFET IRF520 o relevador 5 V (opcional, reposo profundo) | 1 | UNIT | 40 |

### Dónde comprar

- **UNIT Electronics** (uelectronics.com): la electrónica en un solo pedido. Ya están ahí los motores, IMU, servos, buck, capacitores, cámara y NeoPixel.
- **Amazon MX**: lo que UNIT no tiene: DRV8871 (AMONIDA), LiPo Hilldow u Ovonic, PAM8403 en pack.
- **Geek Factory** (geekfactory.mx o Mercado Libre): alternativa para LiPo, cargador y audio.
- **Mercado Libre**: mecánica y misceláneos; filtrar por envío Full. Para la esfera, si no imprimes, buscar "esfera acrílica 30 cm en dos mitades" ($400–800) o pedirla en una acrilería local.
- **Steren**: tienda física para fuente, cables, interruptor, fusibles y lo que falte el mismo día.

### Notas de compra

- **DRV8871:** hasta 3.6 A y 45 V, sobra para el JGB37. Trae terminales de tornillo; el límite de corriente se fija con una resistencia en la placa. Comprar 3 por si uno sale malo. El DRV8833 de UNIT no sirve: máx. 10.8 V y 1.5 A por canal.
- **MG996R:** en UNIT elegir la opción "MG996R DIGI HI-TORQUE", no la MG995.
- **Buck LM2596:** comprar el módulo armado, no el chip. Ajustar la salida a 5.1 V y girar el preset de corriente al máximo antes de conectar la Pi; 2 A reales sin disipador.
- **Condensadores:** en UNIT es un listado con varios valores: elegir 1000 µF (12 × 8 mm). Pata larga a +5 V.
- **Cámara OV5647:** con 5 MP sobra, el agente manda fotos pequeñas. Verificar que incluya el cable de 15 pines para Zero (\~$40 aparte). Los LED IR se pueden desconectar si calientan.
- **NeoPixel:** la versión de 45 mm, no la de 68 mm (no cabe en la cabeza). 16 LED a blanco pleno piden \~1 A: alimentar del power bank y limitar brillo al 30 %. Datos por GPIO18 de la Pi Zero.
- **Ruedas:** la "Llanta de Goma 65 mm" de UNIT es para motor TT (eje 3 mm), no entra en el JGB37. Buscar "rueda 65 mm cople hexagonal 6 mm" o el kit JGB37 con rueda y soporte (Tecneu, Amazon). Forrar con cinta de silicona.
- **Ball transfer:** de bola metálica, 1″; resbala mejor sobre el casco que una rueda loca. No está en UNIT; sí en Mercado Libre y Sonrobots.
- **Melamina:** disco de Ø 20–22 cm con dos muescas para las ruedas; 3 mm de MDF era muy delgado.
- **LiPo 5200 mAh:** 2.5–3 h de uso activo; con 2200 mAh serían 1–1.5 h. Preferir XT60 (Hilldow, 450 g, 139 × 47 × 25 mm); si es Ovonic con Deans T, comprar adaptador Deans→XT60. Montada en el fondo hace de lastre.
- **Cargador:** buscar "cargador balanceador", no "LiPo". Elegir la versión AC (se enchufa a la pared). Cargar la 3S a 2.6 A (0.5C) en modo Balance.
- **Alarma de voltaje:** viene en 3.3 V/celda; subir a 3.5 V alarga la vida de la batería. Se enchufa al JST-XH y el buzzer se oye a través de la esfera.
- **PAM8403:** alimentar a 5 V del power bank, nunca a 11.1 V. Un canal en mono con el altavoz de 4 Ω. La Pi Zero no trae salida de audio: usar I2S (MAX98357) o un DAC USB barato.
- **Power bank 18650:** 97 × 26 mm, 63 g. Se apaga solo si la carga baja de \~100 mA; con el NeoPixel al 30 % no hay problema, si no, usar celda + TP4056 directo.
- **HC-05:** versión maestro/esclavo de 6 pines. Solo si la Pi y el Arduino van sin cable.
- **VL53L1X:** 4 cm–4 m para el freno reflejo; el VL53L0X (2 m) también sirve y es más barato.

## 4. Mecánica interna

Una plataforma con dos ruedas motrices sube por la pared interior de la esfera y la hace rodar; el lastre abajo la mantiene derecha y un poste con imanes arriba sujeta la cabeza a través del casco. Tomado del BB-8 de nachumtwersky en Instructables (2021), escalado a 30–35 cm.

```mermaid
flowchart TD
  H[Cabeza: cúpula + 3 ruedecitas<br/>4 imanes elevados 2 mm] -. atracción magnética .-> P
  P[Poste central<br/>4 imanes N42, cara N arriba] --> B[Base melamina 20–22 cm]
  B --> R[2 ruedas 65 mm<br/>JGB37 + cople hex]
  B --> T[2 ball transfers 1″<br/>a 90° de las ruedas]
  B --> L[LiPo 450 g + lastre<br/>hasta 1–1.5 kg, abajo]
```

| Elemento | Especificación | Por qué |
| --- | --- | --- |
| Base | Disco de melamina 12–15 mm, Ø 20–22 cm, dos muescas para las ruedas | Con 1.5 kg encima, 3 mm de MDF se pandea |
| Ruedas motrices | 2 × 65 mm goma, cople hexagonal eje D 6 mm, forradas con silicona | Contacto contra el casco; el cople es lo que casi nadie compra |
| Apoyo | 2 ball transfers 1″ a 90° de las ruedas, misma altura de contacto | Si tocan antes que las ruedas, la esfera no rueda |
| Lastre | LiPo 450 g + pesas hasta 1–1.5 kg, lo más abajo posible | Los imanes tiran hacia arriba; sin lastre se voltea |
| Poste | Tubo PVC 25 mm o varilla roscada 1/4″, portaimanes impreso arriba | Se recorta hasta dejar los imanes a 2–3 mm del casco |
| Imanes cuerpo | 4 × N42 20 × 5 mm avellanados, tuercas de nylon, cara N arriba | Los 8 de la lista alcanzan: 4 abajo, 4 arriba |
| Imanes cabeza | 4 iguales, cara S abajo, elevados sobre 3 ruedecitas | Si rozan el casco arruinan la pintura y frenan el giro |
| Giro de cabeza | MG996R a rotación continua en el poste; el portaimanes gira con él | La cabeza sigue al imán, no hace falta motor arriba |
| Interruptor | Rocker 10 A accesible desde una tapa del casco | Apagar sin abrir la esfera |

**Reglas que aprendió a golpes el Instructable**

- Probar que la base rueda dentro de la esfera **antes** de poner imanes y lastre; si las ruedas giran pero la esfera no, los ball transfers tocan primero.
- Los imanes N42 de 20 mm lastiman dedos y rompen piezas impresas; separarlos con una cuña de madera, nunca deslizando.
- Reforzar el casco impreso por dentro (resina o fibra) antes de pintar: pegado borde con borde no basta.
- El autor terminó añadiendo un IMU para PID contra el bamboleo al frenar; el MPU6050 y la rampa de la Parte 3 lo resuelven desde el inicio.

## 5. Electrónica y alimentación

Una sola batería para el cuerpo, con la Pi aislada de los picos de los motores; la cabeza lleva su propia batería porque va unida solo por imanes. Hasta la Parte 6 la LiPo se sustituye por la fuente de pared de 12 V y la Pi va con su cargador USB.

```mermaid
flowchart LR
  B[LiPo 3S 11.1 V<br/>o fuente 12 V] --> SW[Rocker<br/>+ fusible 5 A]
  SW --> D1[DRV8871 ×2] --> M[Motores 12 V]
  SW --> BK[Buck 5 V] --> C[Cond. 1000 µF] --> PI[Raspberry Pi]
  PI -->|USB| AR[Arduino]
  AR -->|PWM| D1
  BK --> SV[Servo del poste]
```

### Conexiones del Arduino

| Pin | Conecta a | Función |
| --- | --- | --- |
| D5, D6 | DRV8871 motor izquierdo (IN1, IN2) | PWM velocidad y sentido |
| D9, D10 | DRV8871 motor derecho (IN1, IN2) | PWM velocidad y sentido |
| D2, D3 | Encoders A/B | Interrupciones para contar pulsos |
| A4, A5 | MPU6050 (SDA, SCL) | I2C, inclinación; pin INT para despertar |
| D7 | Servo del poste | Giro de cabeza |
| D8 | Módulo MOSFET (opcional) | Corta la 5 V de la Pi en reposo profundo |
| USB | Raspberry Pi | Serial 115200 baudios |
| GND | Común a todo | Una sola masa |

### Reglas que evitan problemas

- Masa común: todos los GND unidos (fuente, Pi, Arduino, drivers), o el serial dará basura.
- La Pi nunca alimenta motores ni servos; solo el buck lo hace.
- Condensador de 1000 µF en la entrada 5 V de la Pi para que no se reinicie al arrancar los motores.
- Nunca descargar la LiPo por debajo de 3.3 V por celda (\~10 V); la alarma de voltaje se encarga.
- Fusible entre batería e interruptor: si algo se cruza dentro de la esfera no lo ves hasta que huele.
- Autonomía con 5200 mAh: 2.5–3 h de uso activo (ver Modo reposo).

### Cómo se carga sin abrir la esfera

Uno de los seis círculos naranjas del casco es una tapa desmontable (imanes o dos tornillos). Detrás, en un soporte impreso, quedan a la mano el rocker, un **XT60 hembra de panel** y un **JST-XH 4 pines de panel**, ambos con extensiones a la LiPo. Para cargar: apagar el rocker, abrir la tapa, enchufar el B6AC a los dos conectores y cargar en modo Balance a 2.6 A (\~2 h). La batería nunca sale del robot.

```mermaid
flowchart LR
  LIPO[LiPo 3S] -->|XT60 extensión 30 cm| PX[XT60 panel]
  LIPO -->|balanceador extensión| PB[JST-XH panel]
  LIPO --> SW[Rocker] --> ROBOT[Fusible → drivers y buck]
  PX -.->|solo al cargar| B6[iMAX B6AC]
  PB -.-> B6
```

- El rocker debe estar apagado al cargar: el B6AC se confunde si el robot consume mientras carga.
- La alarma de voltaje va al mismo JST-XH de panel con un divisor en Y, para desconectarla cuando guardes el robot.
- Cabeza: el power bank 18650 se carga por micro-USB; una extensión de 15 cm llega a un puerto trasero de la cúpula, bajo la antena. \~3 h con cualquier cargador de teléfono.
- Descartado: cargador integrado con jack DC (no balancea celdas) y contactos pogo en el casco (una esfera no tiene "abajo" fijo).
- *Base de carga inductiva (opcional, después de la Parte 6):* la plataforma interna siempre cuelga hacia abajo, así que una bobina receptora bajo ella y una transmisora en una cuna se alinean solas a través del casco, como en el Sphero. Módulo inalámbrico 12 V / 15–30 W, cargador 3S CC/CV con balanceo ($150), diodo ideal, cuna impresa Ø 12 cm. A 15 W, 5–7 h para 5200 mAh. Que regrese sola a la cuna es otro proyecto.

## 6. Software: cómo se mueve

El LLM decide *qué* hacer; nunca maneja. Tres capas, cada una con su propio reloj, y la regla es que **ninguna capa lenta puede bloquear a una rápida**: el Arduino frena solo aunque la Pi esté esperando a Claude.

| Capa | Dónde | Ciclo | Qué hace | Qué no hace |
| --- | --- | --- | --- | --- |
| Reflejos | Arduino | 10 ms | Rampa, velocidad por encoders, freno si la IMU pasa de 35° o el ToF marca < 25 cm, watchdog de 500 ms | Decidir a dónde ir |
| Servicio de movimiento | Pi principal, Python | 50 ms | Traduce `move(1.0)` y `turn(90)` en `M`; cuenta encoders e integra el giroscopio; devuelve `done` o `blocked` | Interpretar lenguaje |
| Agente | Claude vía MCP | 1–4 s | Elige la siguiente herramienta según lo que ve y oye | Tocar motores |

```mermaid
sequenceDiagram
  participant U as Erick
  participant A as Claude (agente)
  participant S as Servicio (Pi)
  participant F as Arduino
  U->>A: "ven acá"
  A->>S: turn(-40) [ángulo del micrófono]
  S->>F: M -60 60 … M 0 0
  S-->>A: done (1.2 s)
  A->>S: take_photo()
  S-->>A: persona al centro, lejos
  A->>S: move(1.0)
  S->>F: M 70 70
  Note over F: ToF < 25 cm → M 0 0 sin preguntar
  S-->>A: blocked a 0.6 m
  A->>U: "ya llegué" (pitido)
```

| Evento | Quién reacciona | Tiempo | Por qué ahí |
| --- | --- | --- | --- |
| Pared a 25 cm, escalón, alguien lo empuja | Arduino (ToF + IMU) | < 20 ms | El LLM tarda segundos; para entonces ya chocó |
| Obstáculo que la cámara ve a 1 m | Servicio de movimiento | \~200 ms | Frena, devuelve `blocked`, Claude decide rodear o preguntar |
| Se pierde la conexión con la Pi | Arduino (watchdog) | 500 ms | Sin comandos nuevos = alto total |
| Orden nueva o cambio de plan | Claude | 1–4 s | Solo decide entre movimientos ya seguros |
| "Alto" por voz | Wake word + palabra clave | \~300 ms | openWakeWord con "BB-8 alto" como segunda wake word que manda `stop` directo |

Lo que hace tolerable esperar 1–4 s al agente: cada herramienta es **corta y auto-contenida**. `move(1.0)` avanza un metro y se detiene solo; no hay un motor girando mientras Claude piensa. Si el usuario habla a mitad de un movimiento, el servicio termina el paso actual (máximo 1.5 s) antes de atender la orden nueva; un "alto" cancela de inmediato.

Lo que no va a tener: mapa de la casa, memoria de dónde está el sillón, "ve a la cocina". Eso requiere SLAM, otro proyecto. Todo lo relativo a lo que ve y oye ahora mismo (ir hacia quien habla, seguir a alguien, rodear una silla, dar una vuelta) sí sale con lo de la lista.

### Firmware del Arduino

1. Parser de líneas serial: lee hasta `\n`, separa por espacios, primer token = comando.
2. `M <izq> <der>`: velocidad objetivo de cada rueda, −255…255.
3. Lazo PID cada 10 ms con los encoders para que ambas ruedas vayan a la velocidad pedida.
4. Rampa de aceleración (máx. 30 unidades por ciclo) para que la esfera no vuelque al arrancar.
5. Watchdog: sin comando en 500 ms → frena.
6. MPU6050: inclinación > 35° → frena y responde `ERR tilt`. ToF (vía la Zero) < 25 cm → frena y responde `ERR obstacle`.
7. `?` devuelve estado en una línea; `Z`/`W` duermen y despiertan (ver Modo reposo).

### Protocolo serial (Pi → Arduino, 115200 baudios)

```
M <izq> <der>    velocidad por rueda, -255..255
H <ángulo>       giro del poste (cabeza), grados
S                parar
?                estado → "OK V=11.6 T=3 E=142,139"
Z / W            dormir / despertar
```

El Arduino contesta `OK` o `ERR <motivo>` a cada línea. Al firmware no le importa quién origina la orden; la prioridad mando/LLM vive solo en el servicio.

### Servicio de movimiento (Pi, Python, \~200 líneas)

- Único dueño del puerto serial. API interna por socket Unix o HTTP local: `move(m)`, `turn(deg)`, `stop()`, `look_at(deg)`, `get_pose()`.
- Árbitro: si el mando ha enviado algo en el último segundo, las órdenes del LLM se rechazan con `manual_override`; al soltarlo, el LLM recupera el control.
- Cola serial única: una orden en curso a la vez; `stop` salta la cola.
- `move(1.0)` → pulsos de encoder objetivo (65 mm de rueda ≈ 4.9 vueltas/m, con factor de deslizamiento calibrado) → `M` hasta alcanzarlos; `turn` integra el giroscopio.
- Mando Bluetooth con `evdev`, mezcla arcade (`izq = y + x`, `der = y − x`), zona muerta ±10.
- Lee la cámara a 5 fps y marca "obstáculo al frente"; devuelve `blocked` con la distancia.
- Límites de seguridad en un solo sitio: velocidad máxima (PWM 50–60 % con los motores de 319 RPM), duración máxima de una orden (5 s), parada si el Arduino responde `ERR`.

### Servidor MCP `bb8-motion`

Escrito con el SDK de Python para MCP (`FastMCP`): cada herramienta es una función decorada que llama al servicio de movimiento o a la Zero. Transporte `streamable-http` en el puerto 8765 para conectarse desde otra máquina; `stdio` si solo lo usa el agente local. El agente de voz es un cliente más; también puedes conectarlo a Claude Desktop o Claude Code y conducir el robot desde el portátil. Las descripciones de las herramientas son la parte importante: le dicen a Claude que mire antes de avanzar en sitio nuevo y que no encadene más de tres movimientos sin preguntar.

| Herramienta | Parámetros | Qué hace |
| --- | --- | --- |
| `move` | metros (−2…2) | Avanza con encoders; devuelve metros reales o `blocked` |
| `turn` | grados (+ derecha, − izquierda) | Giro sobre sí mismo con giroscopio |
| `stop` | — | Frena, salta la cola |
| `look_at` | grados | Gira el poste; la cabeza sigue al imán |
| `take_photo` | — | Foto de la Zero a 640 px, devuelta como imagen |
| `set_eye_color` | color, patrón | Anillo NeoPixel |
| `say` | texto o sonido (feliz, triste, alerta, pregunta) | Piper o WAV en el altavoz de la cabeza |
| `get_pose` | — | Batería, inclinación, distancia ToF, quién controla |

### Personalidad (system prompt)

- Habla poco y con pitidos entre palabras; curioso, leal, algo cabezota.
- Antes de moverse en un sitio nuevo usa `take_photo` para no chocar; nunca más de 1 m sin volver a mirar.
- Si el mando está activo, no insiste: "el piloto manda".
- Si `get_pose` marca inclinación alta o batería baja, lo avisa y se para.
- Saluda por nombre a las voces registradas y no obedece órdenes de movimiento de desconocidos.
- Responde en español; frases de menos de 15 palabras porque irán a TTS.

### Voz e identificación

| Problema | Cómo | Dónde corre | Costo |
| --- | --- | --- | --- |
| Detectar que le hablan | openWakeWord ("oye BB-8", \~10 % CPU) → Silero VAD graba hasta 0.8 s de silencio → faster-whisper `small` transcribe (2–4 s) | Pi principal, sin internet | 0 |
| Saber quién habla | Embedding de voz (Resemblyzer o ECAPA): 3 s de audio → vector de 256; similitud > 0.75 contra las voces registradas → "Habla Erick" en el system prompt | Pi principal, en paralelo (\~0.3 s) | 0 |
| Saber de dónde viene la voz | ReSpeaker 2-Mic HAT: da el ángulo y cancela el eco del propio altavoz. Plan B: la cabeza barre hasta que la cámara ve una cara | HAT sobre la Pi principal | \~$450 |

- Registro de voces: cada persona dice 3–4 frases una vez; se guarda el promedio de embeddings en `voices.json`. No es biometría segura, pero basta para saludar por nombre y guardar preferencias.
- El ReSpeaker sustituye al micrófono USB: sin cancelación de eco, BB-8 se oye a sí mismo y dispara su propia wake word.
- Toda la voz se procesa en la Pi; solo el texto transcrito y las fotos van a Claude.

### Stack en la Pi

| Función | Herramienta | Por qué |
| --- | --- | --- |
| Wake word | openWakeWord | Local, ligero |
| STT | faster-whisper `small` | Buen español, corre en Pi 4/5 |
| LLM | Claude API con tool use | Decide acciones de forma fiable |
| TTS | Piper (voz es\_ES) | Local y rápido |
| Serial | pyserial | Estándar |
| MCP | FastMCP | Mismas herramientas para voz, Desktop y Code |
| Cabeza | Flask en la Zero | `/foto`, `/hablar`, `/tof`, `/ojo` |

### Modo reposo de bajo consumo

Dos niveles: *reposo ligero*, donde la Pi sigue escuchando la wake word y el resto se apaga por software; y *reposo profundo*, donde la Pi se apaga del todo y el Arduino queda dormido vigilando la IMU. Con la LiPo de 5200 mAh:

| Estado | Qué está encendido | Consumo | Autonomía |
| --- | --- | --- | --- |
| Activo | Todo, motores en movimiento | 1.5–2 A | 2.5–3 h |
| Escuchando | Pi + micrófono, motores frenados, ojo al 30 % | \~0.6 A | \~8 h |
| Reposo ligero | Pi con WiFi; cámara y ojo apagados, servo sin PWM, drivers en sleep | \~0.25 A | \~20 h |
| Reposo profundo | Solo Arduino dormido + IMU + alarma de voltaje | \~15 mA | Días |

```mermaid
stateDiagram-v2
  [*] --> Activo
  Activo --> Escuchando: 30 s sin comando
  Escuchando --> ReposoLigero: 5 min sin voz ni movimiento
  ReposoLigero --> ReposoProfundo: 30 min, o "BB-8, a dormir"
  Escuchando --> Activo: wake word / comando MCP
  ReposoLigero --> Activo: wake word / comando MCP / IMU detecta movimiento
  ReposoProfundo --> Activo: IMU detecta movimiento (Arduino enciende la Pi, ~25 s)
```

*Reposo ligero* no necesita hardware extra:

- Drivers: el DRV8871 entra solo en sleep (<10 µA) con IN1 = IN2 = 0 por más de 1 ms; basta `M 0 0`.
- Servo: `servo.detach()` quita el PWM y baja de \~100 mA a \~5 mA; al despertar, `attach()` y mover despacio a la última posición.
- Ojo: NeoPixel en negro (\~16 mA); una respiración azul al 3 % cuesta menos de 30 mA si quieres que se note que duerme.
- Cámara: cerrar el proceso de captura; en idle consume \~150 mA.
- Pi Zero 2 W: `cpufreq` en `powersave`, Bluetooth apagado, HDMI desactivado (`tvservice -o`) bajan \~60 mA. No apagar el WiFi: es la vía para despertarla por MCP.
- Comandos `Z` (dormir) y `W` (despertar) que el firmware traduce en lo anterior.

*Reposo profundo* necesita el **módulo MOSFET o relevador de 5 V** entre el buck y la Pi, controlado por D8 del Arduino:

- La Pi hace `shutdown -h` limpio y avisa al Arduino; 10 s después el Arduino corta su alimentación (una Pi apagada pero conectada sigue consumiendo \~50 mA).
- El Arduino entra en `SLEEP_MODE_PWR_DOWN` (\~10 mA en Nano/Uno; <1 mA en Pro Mini sin LED) y despierta por la interrupción de movimiento del MPU6050.
- Al despertar cierra el MOSFET, la Pi arranca en \~25 s y BB-8 pita "me desperté". Si el retraso molesta, quedarse en reposo ligero.
- La alarma de voltaje sigue conectada al balanceador y suena aunque todo duerma.

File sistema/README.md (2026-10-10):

# Sistema

Servicios systemd e instaladores. Ambos instaladores esperan el repo en `/home/bb8/bb8`.

| Archivo | Va en | Hace |
| --- | --- | --- |
| `instalar_pi.sh` | Pi principal (Pi 3, OS de 64 bits) | Usuario `bb8`, venv, dependencias, `pip install -e .`, voz de Piper, zram y `gpu_mem=16` con 1 GB, servicios |
| `instalar_zero.sh` | Pi Zero 2 W | picamera2, venv, Piper, servicio de la cabeza |
| `bb8-motion.service` | Pi principal | `python -m bb8.motion_api --mando` (Parte 3) |
| `bb8-mcp.service` | Pi principal | `python -m bb8_mcp` (Parte 4) |
| `bb8-voz.service` | Pi principal | `python -m voz` (Parte 4) |
| `bb8-energia.service` | Pi principal | `python -m energia` (Parte 6) |
| `bb8-cabeza.service` | Pi Zero | `python -m head.server` (Parte 5) |
| `bb8.env.ejemplo` | `/etc/bb8.env` | API key y ajustes `BB8_*` |

Guía: [wiki/Instalacion-en-la-Pi.md](../wiki/Instalacion-en-la-Pi.md)

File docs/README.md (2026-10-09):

# Documentos y artefactos

| Archivo | Qué es |
| --- | --- |
| [`proyecto-bb8-agente-llm.md`](proyecto-bb8-agente-llm.md) | Documento técnico original (19 sep 2026): arquitectura, plan, materiales, mecánica, electrónica, software, reposo |
| [`artefactos/documento-tecnico.html`](artefactos/documento-tecnico.html) | El mismo documento en HTML |
| [`artefactos/diagramas.html`](artefactos/diagramas.html) | Cableado, alimentación, comunicación, secuencia del agente, simulación |
| [`artefactos/avance-del-proyecto.html`](artefactos/avance-del-proyecto.html) | Tracker de fases, tareas y compras |
| [`artefactos/mecanica-bb8.html`](artefactos/mecanica-bb8.html) | Corte animado del mecanismo interno |
| [`artefactos/animacion-bb8-en-casa.html`](artefactos/animacion-bb8-en-casa.html) | Animación 2D con música |

Los HTML se ven descargándolos y abriéndolos en el navegador. El documento técnico
asume el DRV8871; donde no coincida con el código, mandan el código y
[wiki/Protocolo.md](../wiki/Protocolo.md). Más en [wiki/Artefactos.md](../wiki/Artefactos.md).

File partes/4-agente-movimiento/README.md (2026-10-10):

# Parte 4 · Agente controla el movimiento

El servidor MCP que le da a Claude las herramientas del robot y el agente de voz.

```
bb8_mcp/                servidor MCP bb8-motion (FastMCP, :8765/mcp); personalidad en head/personalidad.py
voz/                    wake word → VAD → Whisper → Claude + MCP → Piper
├── escucha.py          openWakeWord + Silero VAD
├── stt.py              faster-whisper local o API en la nube (BB8_STT)
├── hablantes.py        registro de voces (Resemblyzer, opcional)
├── agente.py           Claude con las herramientas MCP
├── salida.py           Piper local o en la cabeza, pitidos
└── cara.py             girar hacia quien habla (Parte 5)
wakeword/               entrenar la wake word "oye BB-8" (Colab o PC, no en la Pi)
requirements-voz.txt
```

Desde la raíz del repo, con la Parte 3 corriendo:

```bash
python -m bb8_mcp                                     # luego: claude mcp add --transport http bb8 http://127.0.0.1:8765/mcp
pip install -r partes/4-agente-movimiento/requirements-voz.txt
export ANTHROPIC_API_KEY=sk-ant-...
python -m voz.agente "da una vuelta y dime qué ves"   # sin micrófono
python -m voz.hablantes registrar Erick
python -m voz                                         # el bucle completo
```

**Lista cuando** "Oye Jarvis… ven acá" y se mueve. Para "oye BB-8", entrena el modelo con
[`wakeword/`](wakeword) y copia `oye_bb8.onnx` a `voz/modelos/`.

Guías: [wiki/Parte-4-Agente-controla-el-movimiento.md](../../wiki/Parte-4-Agente-controla-el-movimiento.md) ·
[wiki/Conectar-con-Claude.md](../../wiki/Conectar-con-Claude.md) ·
[wiki/Wake-word-oye-BB-8.md](../../wiki/Wake-word-oye-BB-8.md)

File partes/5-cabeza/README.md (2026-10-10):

# Parte 5 · Agente controla la cabeza

El servidor HTTP de la cabeza, que corre en la Pi Zero 2 W.

```
head/
├── server.py           API :8080 (/estado /foto /tof /ojo /hablar /cara /reposo)
├── backends_real.py    picamera2 (opcional), VL53L0X/L1X, NeoPixel en GPIO18, Piper (sin probar en hardware)
├── backends_sim.py     webcam del PC o vista sintética (la usa el simulador)
├── colors.py           colores y patrones del ojo
├── sounds.py           pitidos de droide sintetizados (15 emociones + balbuceo)
└── personalidad.py     emoción → pitido + ojo, frases cortas y prompt de personalidad
requirements-zero.txt
```

En la Zero (hostname `bb8-head`, I2C y cámara activados):

```bash
sudo git clone https://github.com/erickdsama/bb8 /home/bb8/bb8
cd /home/bb8/bb8 && sudo bash sistema/instalar_zero.sh
curl http://bb8-head.local:8080/estado
```

En la Pi principal, `/etc/bb8.env`: `BB8_VOZ_SALIDA=cabeza` y `BB8_BUSCAR_CARA=1`.
Si el ToF se muda a la cabeza, `USAR_TOF_LOCAL 0` en el firmware.

Casco, plato y soportes impresos de la cabeza: [`cad/`](../../cad).
Escuchar los pitidos en el PC (solo librería estándar):

```bash
python -m head.sounds                       # todos, con su descripción
python -m head.sounds curioso risa          # algunos
python -m head.sounds --texto "¿Quién anda ahí?"
python -m head.sounds --html sonidos.html   # página para oírlos en el navegador
```

**Lista cuando** gira la cabeza hacia ti y describe lo que ve.

Guía completa: [wiki/Parte-5-Agente-controla-la-cabeza.md](../../wiki/Parte-5-Agente-controla-la-cabeza.md)

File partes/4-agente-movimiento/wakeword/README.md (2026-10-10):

# Wake word "oye BB-8"

Entrena el modelo de openWakeWord para que el BB-8 despierte con "oye BB-8" en lugar de
"hey Jarvis". Se corre en Google Colab o en una PC con Linux, no en la Pi.

```
entrenar_oye_bb8.ipynb      cuaderno para Colab: corre todo y descarga oye_bb8.onnx
entrenar.py                 pasos: datos, muestras, aumentar, modelo (o todo)
oye_bb8.yml                 frases, voces, cantidades y parámetros de entrenamiento
muestras.py                 "oye BB-8" y frases parecidas con las voces de Piper en español
datos.py                    eco, ruido y negativos genéricos de Hugging Face
lanzar_train.py             openwakeword/train.py con parches para torch/torchaudio nuevos
probar.py                   mide un modelo: archivos, horas de ruido o micrófono en vivo
sin_generador/              sustituto de piper-sample-generator (train.py lo importa siempre)
requirements-entrenar.txt
```
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

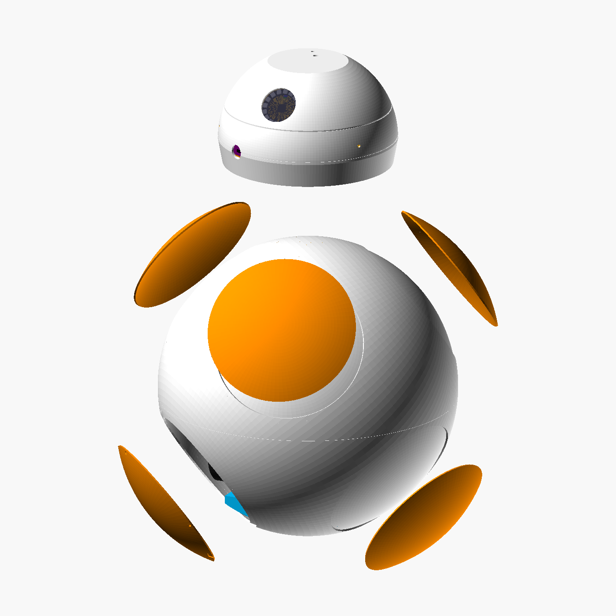
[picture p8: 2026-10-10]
cad/png/bb8_explosion.png

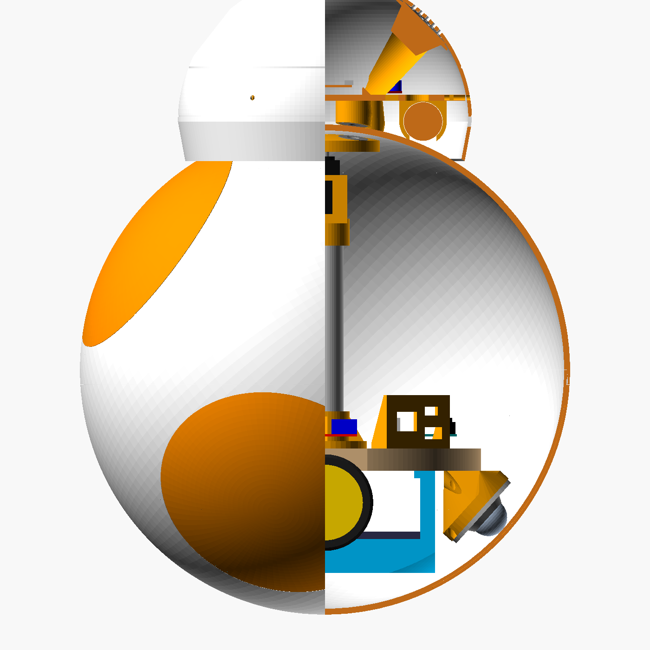
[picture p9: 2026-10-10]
cad/png/bb8_corte_lateral.png

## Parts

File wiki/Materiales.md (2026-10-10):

# Materiales

## Ya comprado: pedido UNIT Electronics 377466 (8 oct 2026)

Total MXN 1,898.25 con envío (Estafeta). Precios por unidad.

| Pieza | Cant. | MXN | Parte |
| --- | --- | --- | --- |
| Motorreductor JGB37-520B 12 V 319 RPM con encoder | 2 | 231 | 1 |
| Driver L298N (uno de repuesto) | 2 | 59 | 1 |
| IMU MPU6050 6 DOF | 1 | 87 | 1 |
| Servo MG996R engranes metálicos (uno de repuesto) | 2 | 114 | 1 |
| Buck LM2596 ajustable 3 A | 1 | 42 | 1 |
| Sensor ToF láser VL53L0X I2C | 1 | 47 | 1 |
| Condensador electrolítico 1000 µF 16 V | 4 | 3 | 1 |
| Adaptador 12 V 2 A + par plug/jack DC | 1 | 83 + 14 | 1 |
| Protoboard 830 + fuente MB102 + 65 jumpers | 1 | 90 | 1 |
| Anillo WS2812 16 LED 45 mm | 1 | 58 | 5 |
| Amplificador PAM8403 5 V con volumen | 1 | 29 | 5 |
| Bocina 4 Ω 5 W | 2 | 80 | 5 |
| Par de conectores XT60 + par de cables XT60 12 AWG 15 cm | 1 | 18 + 59 | 6 |
| Checador de voltaje LiPo/Li-ion 1–8S | 1 | 53 | 6 |
| 25 tornillos M3×6 con tuerca, separadores de latón M3 (6 de 10 mm, 4 de 5 mm), cable 22 AWG rojo/negro 2 m c/u, termorretráctil 328 pzs, cinta doble cara 5 m | — | — | 2 |

**Cambio respecto al documento técnico:** el L298N reemplaza al DRV8871. Si se
calienta, el respaldo es un BTS7960. El L298N tira ~2 V, así que el motor ve ~10 V
(~0.9 m/s máx.). Pinout en [Protocolo](Protocolo.md#cambio-por-el-l298n).

## Falta comprar: cotización del 9 oct 2026

Precios en MXN tomados de las fichas de cada tienda el 9 de octubre de 2026, sin envío;
cambian seguido, así que confirma antes de pagar. "Est." es un estimado sin ficha
consultada (tienda física o sin precio visible). Nada de esto se ha comprado.

### Carrito recomendado, ahora (Partes 2, 4 y 5)

Se puede pedir ya; nada depende del tamaño final de la esfera.

| Pieza | Cant. | Tienda | MXN | Nota |
| --- | --- | --- | --- | --- |
| [Llanta de goma 65 mm con accesorios](https://uelectronics.com/producto/llanta-de-goma-65mm/) (ASLONG, Ø 69 × 27 mm, buje hexagonal 12 mm) | 2 | UNIT | 165 c/u | Elegir la variante **con accesorios** (buje, escuadra metálica, tornillo M4); la sencilla cuesta 84 y no trae buje. UNIT la anuncia para el JGB37-520B. No trae llave Allen |
| [Soporte en L para motor 37 mm](https://articulo.mercadolibre.com.mx/MLM-652432552-soporte-motorreductor-bracket-37d-37gb-en-l-_JM) | 2 | Mercado Libre | ~40 c/u (est.) | Solo si la escuadra de la llanta no sirve para fijar el motor a la melamina. Alternativa: [uxcell, 4 pzs](https://www.amazon.com.mx/uxcell-Soporte-reductor-engranajes-unidades/dp/B07QX82WS2) en Amazon |
| Ball transfer 1″ de acero, montaje de 2 tornillos ([TruePower, 6 pzs](https://www.amazon.com.mx/TruePower-Roller-Ball-Transfer-Bearings/dp/B009KASQZW)) | 2 | Amazon | ~120 (est.) | Vienen en paquete; sobran para la cabeza o repuesto |
| Melamina 12–15 mm 30 × 30 cm, tubo PVC 25 mm o varilla 1/4″ + tuercas | 1 | Maderería, ferretería | ~120 (est.) | |
| [Micrófono USB mini SunFounder](https://www.amazon.com.mx/SunFounder-Micr%C3%B3fono-Raspberry-computadora-reconocimiento/dp/B01KLRBHGM) | 1 | Amazon | 191 | Para la Pi principal (Parte 4) |
| [Cámara Arducam OV5647 5 MP](https://www.amazon.com.mx/Arducam-megap%C3%ADxeles-Sensor-OV5647-Raspberry/dp/B012V1HEP4) | 1 | Amazon | 134 | Confirmado: no la tienes. Trae los dos cables, 15 → 15 y **15 → 22 pines**; la Zero 2 W usa el de 22 |
| [Amplificador I2S MAX98357A](https://www.amazon.com.mx/MAX98357A-amplificador-decodificaci%C3%B3n-selecci%C3%B3n-proyectos/dp/B0F1Y3KHJF) | 1 | Amazon | ~85 | Le da audio a la Zero y mueve directo una bocina de 4 Ω (3.2 W). Pack de 2: [DAOKAI](https://www.amazon.com.mx/DAOKAI-unidades-MAX98357-amplificador-decodificador/dp/B0B2NSMV55) 231 |
| [Power bank 1 × 18650, 2600 mAh](https://www.mercadolibre.com.mx/cargador-tipo-power-bank-para-bateria-18650-2600mah-incluida/up/MLMU3701037772) | 1 | Mercado Libre | ~250 (est.) | 97 × 26 mm, 63 g, salida 5 V 1 A, batería incluida. Para la cabeza |
| Imanes neodimio disco 20 × 5 mm, [paquete de 10](https://listado.mercadolibre.com.mx/imanes-de-neodimio-20x5) | 1 | Mercado Libre | ~607 | Hacen falta 8 (4 en el poste, 4 en la cabeza). Revisar que la ficha diga N42; 2 paquetes de 5 salen en ~568 |
| [Rueda loca mini, bola de nylon 1″](https://uelectronics.com/producto/mini-rueda-universal-con-bola-de-nylon/) | 3 | UNIT | 37–51 c/u | Las 3 "ruedecitas" de la cabeza; el nylon no raya la pintura del casco |

**Subtotal ahora: ~$2,050** (~$1,970 sin los soportes de motor).

### Carrito recomendado, después (Parte 6)

Conviene esperar a que la Parte 3 ruede, por si cambia el tamaño de la esfera o el
consumo real de los motores.

| Pieza | Cant. | Tienda | MXN | Nota |
| --- | --- | --- | --- | --- |
| [LiPo 3S 11.1 V 5200 mAh 80C XT60, Hilldow (2 pzs)](https://www.amazon.com.mx/Hilldow-conector-veh%C3%ADculos-Camiones-paquetes/dp/B0FW4WPFNT) | 1 paquete | Amazon | 813 | ~407 por batería: más barato que una sola de [PCEONAMP](https://www.amazon.com.mx/PCEONAMP-capacidad-Quadcopter-Helic%C3%B3ptero-almacenamiento/dp/B0CHJHHK9V) (710). La segunda es repuesto |
| [Cargador balanceador iMAX B6AC 80 W](https://www.mercadolibre.com.mx/cargador-balanceador-imax-b6-b6ac-80w/p/MLM47578491) | 1 | Mercado Libre | 600–750 | La versión **AC** trae fuente interna; la B6 sin AC necesita una fuente de 12 V aparte. [HetPro](https://hetpro-store.com/cargador-de-baterias-lipo-80w/) la tiene en 850 |
| [Switch de balancín con piloto 12 Vcc, 16 A](https://www.steren.com.mx/switch-de-balancin-de-1-polo-1-tiro-2-posiciones-on-off-con-piloto-12-vcc.html) | 1 | Steren | 19 | |
| [Portafusible europeo de cartucho 5 × 20](https://www.steren.com.mx/porta-fusible-europeo-de-cartucho.html) + 3 fusibles 5 A 5 × 20 | 1 | Steren | 15 + ~12 | |
| Buck XL4015 5 A ajustable, para la Pi 3 ([Mercado Libre](https://listado.mercadolibre.com.mx/xl4015)) | 1 | Mercado Libre / UNIT | ~60 | La Pi 3 pide 5.1 V 2.5 A y el LM2596 da ~2 A reales: el XL4015 deja margen. El LM2596 del pedido 377466 se queda solo para el servo. [Versión con medidores en UNIT](https://uelectronics.com/producto/modulo-de-carga-reductor-xl4015-5a-con-medidores/): 140 |
| Cable micro-USB corto y grueso (o pigtail micro-USB macho) | 1 | Steren | ~50 (est.) | Del buck a la Pi 3. Un cable delgado provoca avisos de bajo voltaje; no alimentar por los pines GPIO |
| P-MOSFET AO3401 (SOT-23) | 2 | Mercado Libre | ~80 | Reposo profundo de la Pi; el IRF520 no sirve. Necesita placa adaptadora SOT-23 o soldar fino |
| Resistencias 100 kΩ, 10 kΩ y 4.7 kΩ | — | UNIT / Steren | ~30 (est.) | Pull-up del MOSFET y divisor de batería en A0 |
| XT60 hembra de panel + extensión JST-XH 4 pines | 1 | Amazon / UNIT | ~140 (est.) | Puerto de carga en la tapa del casco |
| Filamento PLA 1.75 mm 1 kg ([Mercado Libre](https://listado.mercadolibre.com.mx/filamento-pla-1.75mm-1kg)) | 3 | Mercado Libre | 220–300 c/u | Marcas genéricas buenas: Kitul, SUNLU, JAYO |
| Primer, pintura blanca/naranja/plata, laca, lijas | 1 | Tlapalería | 300–500 (est.) | |
| Lastre (pesas o plomo) | 200–400 g | Mercado Libre | ~50 (est.) | |

**Subtotal Parte 6: ~$3,170.** Total pendiente con los dos carritos: **~$5,220** más envíos.

### Cámara OV5647

Confirmado el 9 oct 2026: no la tienes y va en otro pedido, así que está en el carrito
de ahora. La
[de visión nocturna de UNIT](https://uelectronics.com/producto/camara-vision-nocturna-raspberry-pi-5mp-1080p-ov5647/)
cuesta 240 pero solo trae cable de 15 pines; con la Zero haría falta además un
[cable 15 → 22](https://www.amazon.com.mx/Onyehn-flexible-c%C3%A1mara-Raspberry-unidades/dp/B07XZ5DX5H).

### Lo que ya no hace falta

- **Bocina o DAC USB para la Pi principal:** ya llegaron 2 bocinas y un PAM8403, y la
  Pi 3 trae jack de 3.5 mm: jack → PAM8403 → bocina.
- **Tarjeta de sonido USB para la Zero:** la reemplaza el MAX98357A del carrito.
- **Cúpula de la cabeza:** sale impresa en la Parte 6 con el PLA.
- **Checador de voltaje LiPo y conectores XT60 macho:** ya vienen en el pedido 377466.

### Notas de la cotización

- **Ruedas:** la "Llanta de Goma 65 mm" de UNIT con accesorios sí es para el JGB37
  (buje hexagonal de 12 mm con prisionero sobre el eje D de 6 mm). La que es para motor
  TT es otra: la "Llanta para Motorreductor TT de 66 × 27 mm".
- **Imanes:** los N42 de 20 mm lastiman dedos y rompen piezas impresas; separarlos con
  una cuña, nunca deslizando.
- **LiPo:** cargar siempre en modo Balance con el B6AC; el checador de voltaje del
  pedido 377466 sirve como alarma.
- Para la versión anterior de la lista, con todas las piezas y tiendas, ver el
  [documento técnico](https://github.com/erickdsama/bb8/blob/main/docs/proyecto-bb8-agente-llm.md#3-materiales).

## Estimaciones

- Peso total 2–2.5 kg.
- Velocidad útil ~0.6 m/s (PWM limitado a ~55 %).
- 2.5–3 h de uso activo con 5200 mAh.

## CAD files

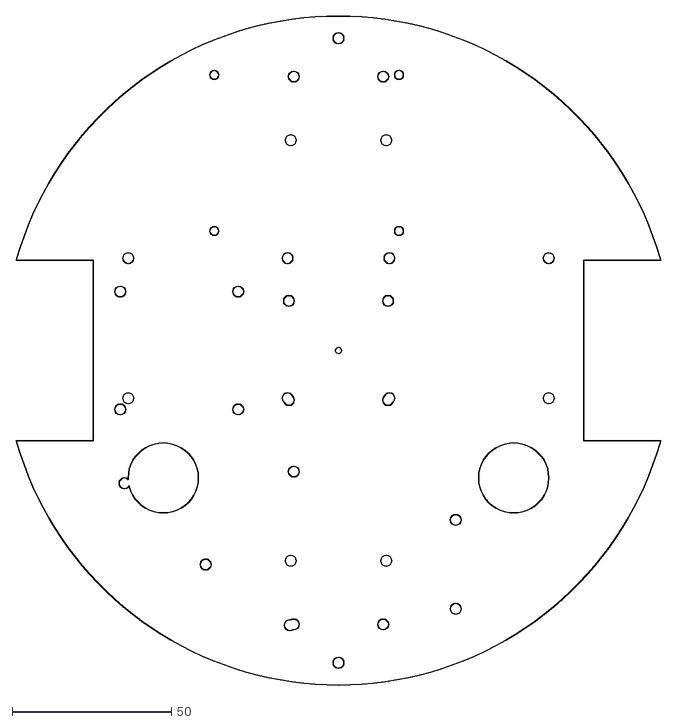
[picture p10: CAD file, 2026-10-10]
cad/plantillas/plataforma.dxf
202.2 x 210.0

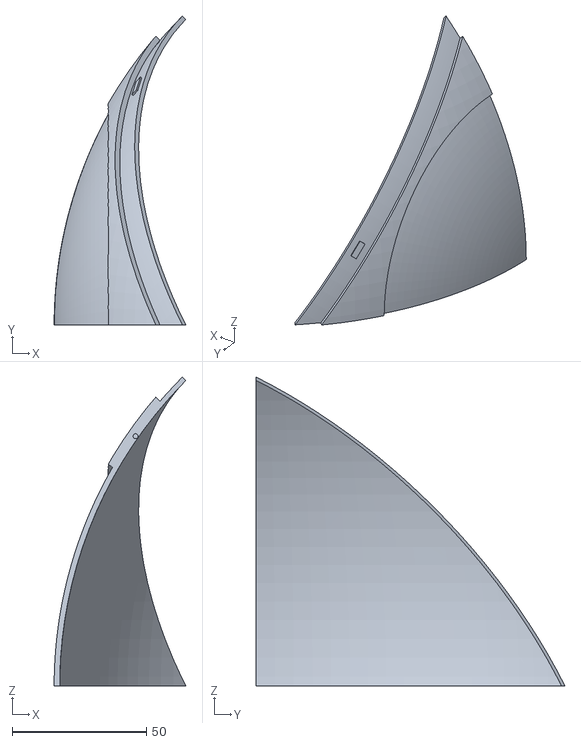
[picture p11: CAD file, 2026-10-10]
cad/stl/esfera_gajo_B_mpp.stl
49.0 x 114.9 x 114.9

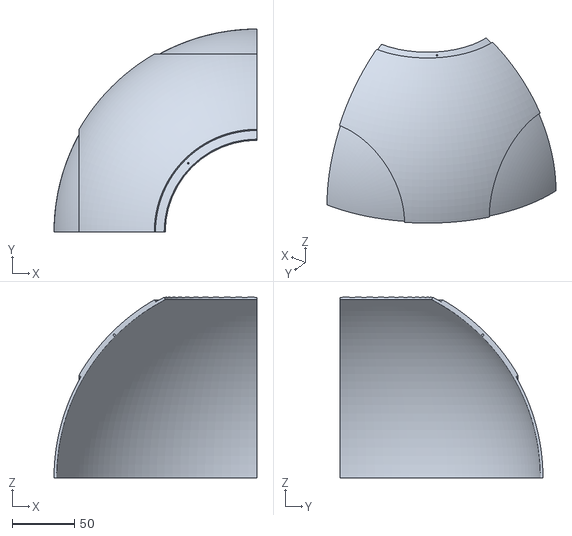
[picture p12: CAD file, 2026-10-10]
cad/stl/esfera_gajo_B_mmm.stl
163.0 x 163.0 x 145.0

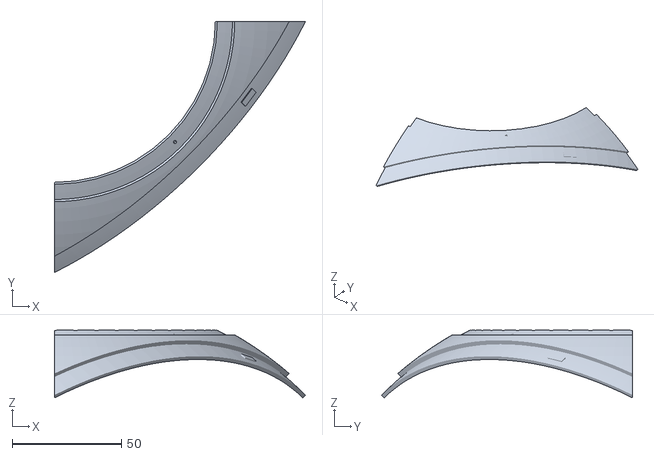
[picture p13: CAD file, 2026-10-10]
cad/stl/esfera_gajo_B_ppm.stl
114.9 x 114.9 x 31.0

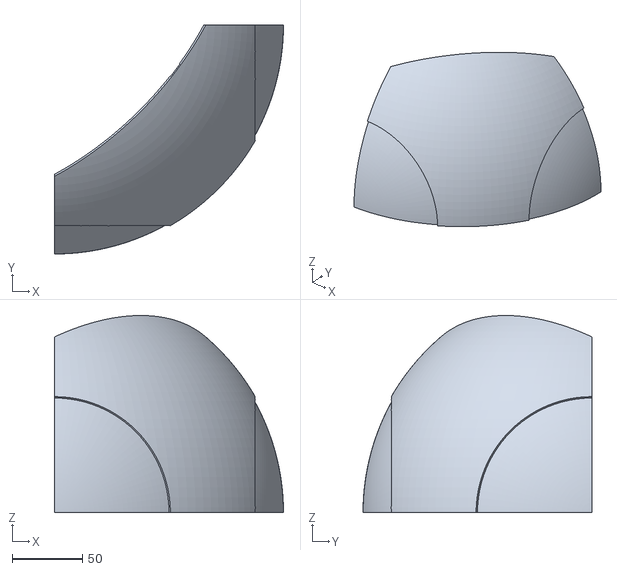
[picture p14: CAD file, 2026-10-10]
cad/stl/esfera_gajo_A_ppm.stl
163.0 x 163.0 x 140.2

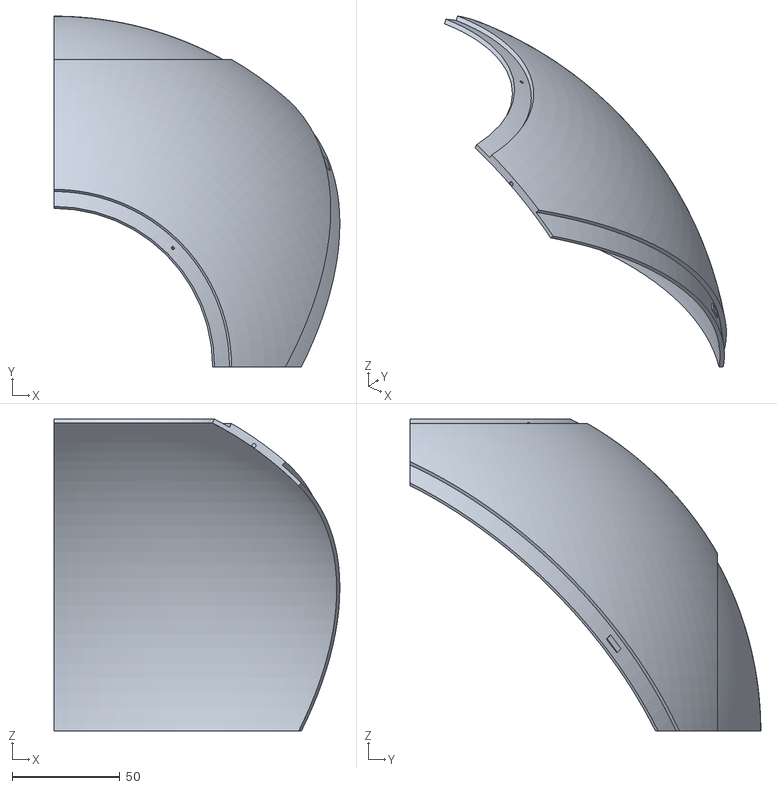
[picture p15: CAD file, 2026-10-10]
cad/stl/esfera_gajo_B_pmm.stl
132.8 x 163.0 x 145.0

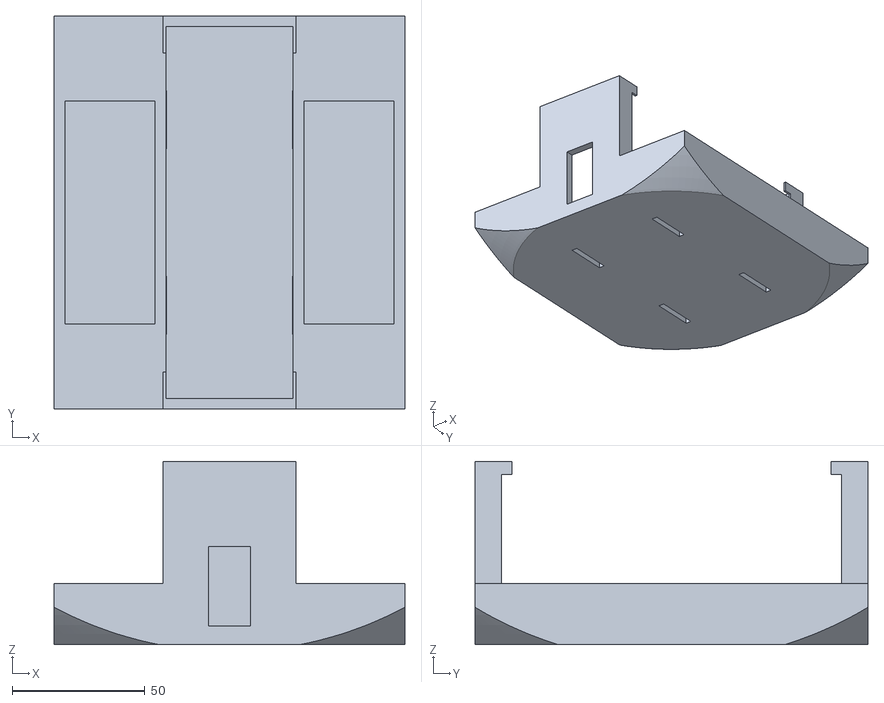
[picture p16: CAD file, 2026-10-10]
cad/stl/base_charola.stl
132.0 x 148.0 x 69.0

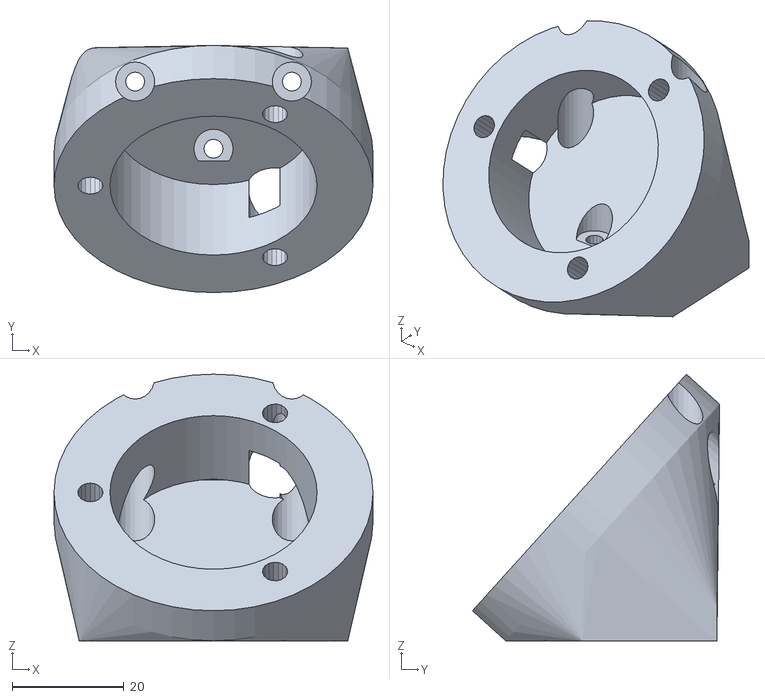
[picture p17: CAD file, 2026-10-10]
cad/stl/base_soporte_bt.stl
57.0 x 44.2 x 47.7

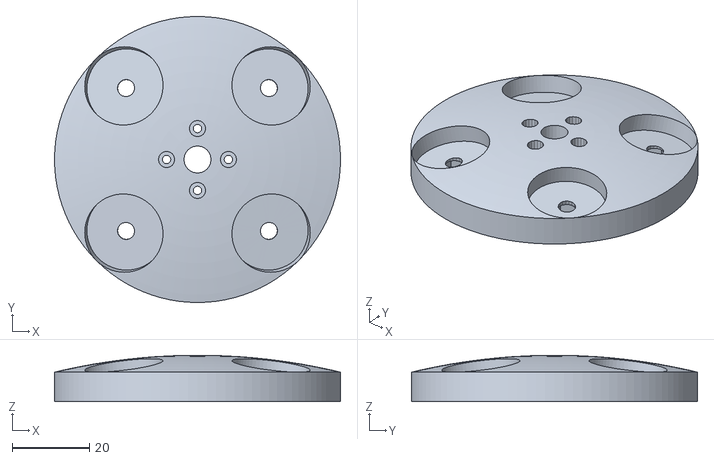
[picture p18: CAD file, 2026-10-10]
cad/stl/poste_portaimanes.stl
74.0 x 74.0 x 11.9

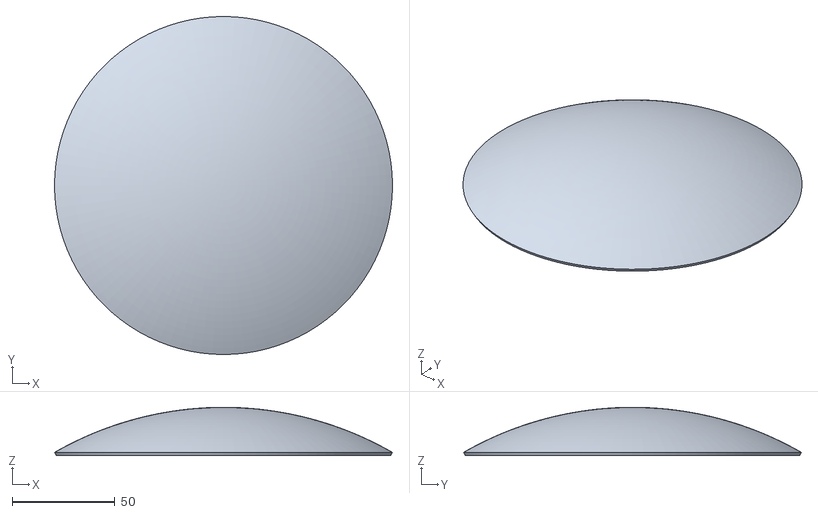
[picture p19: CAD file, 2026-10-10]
cad/stl/esfera_circulo.stl
164.5 x 164.5 x 23.6

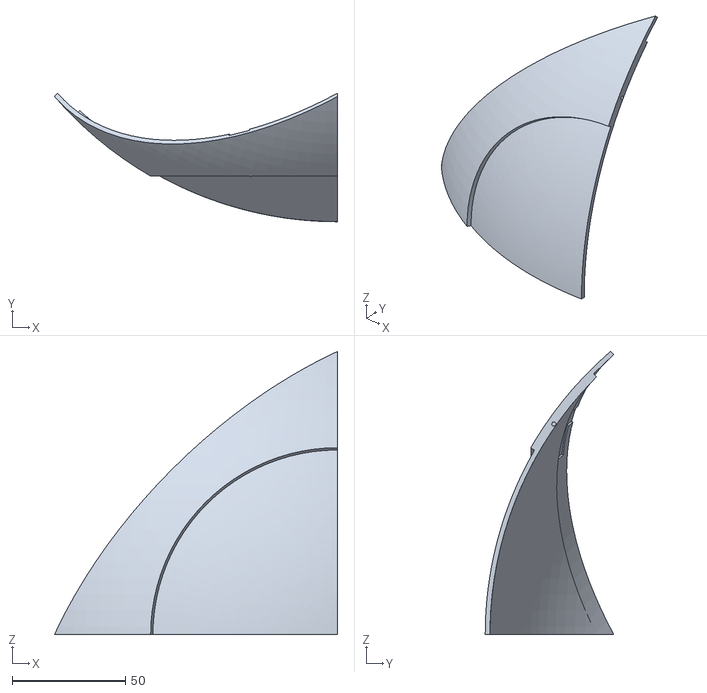
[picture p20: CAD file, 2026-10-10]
cad/stl/esfera_gajo_A_mpm.stl
125.0 x 56.8 x 125.0

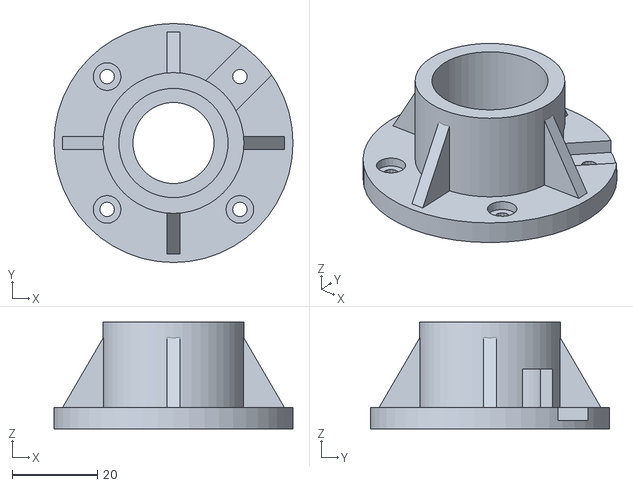
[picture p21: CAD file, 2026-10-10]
cad/stl/poste_pie_poste.stl
56.0 x 56.0 x 25.0

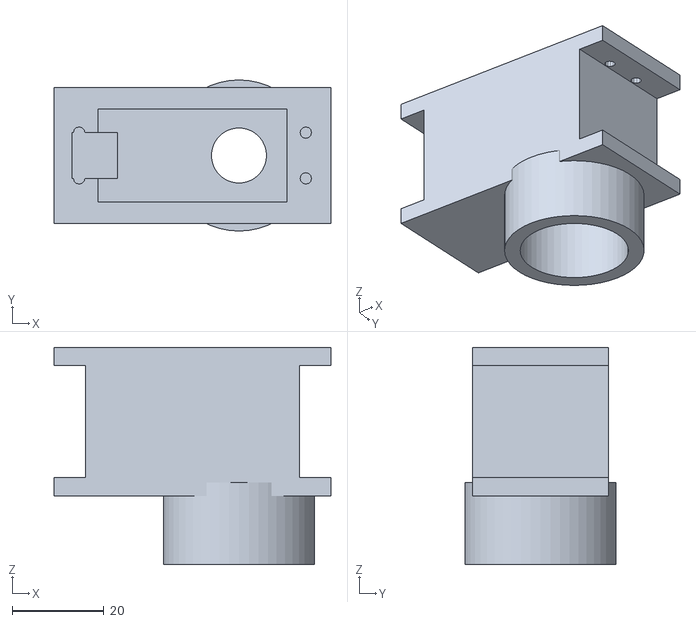
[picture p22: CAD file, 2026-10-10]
cad/stl/poste_soporte_servo.stl
60.5 x 33.0 x 47.5

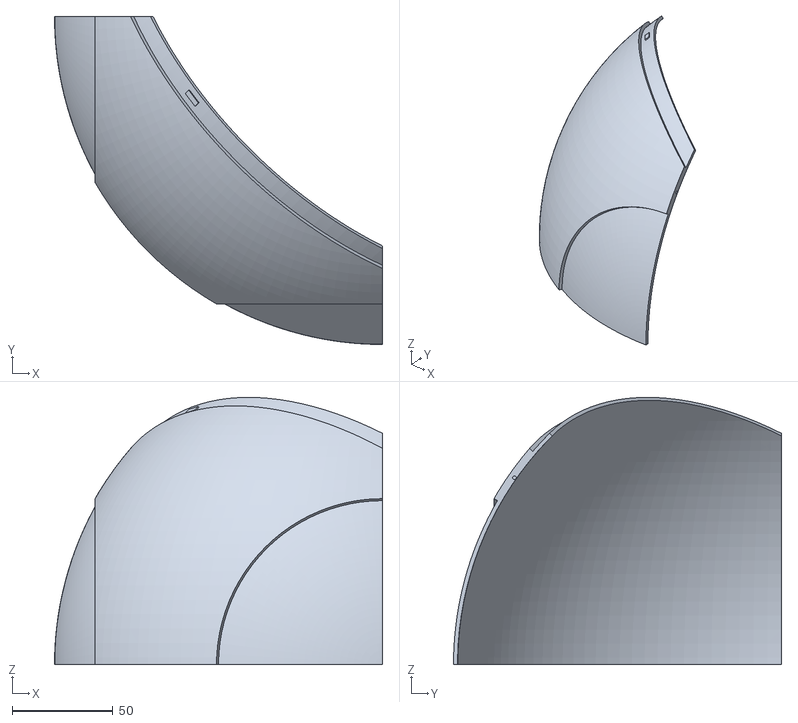
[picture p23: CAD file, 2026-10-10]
cad/stl/esfera_gajo_B_mmp.stl
163.0 x 163.0 x 132.8

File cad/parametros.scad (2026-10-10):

// BB-8 · parámetros compartidos de todas las piezas.
//
// Todas las medidas en mm. Marco del robot (ensamble en reposo):
//   origen = centro de la esfera, +z arriba, +y adelante, +x derecha (eje de las ruedas).
// Cambia un número aquí y vuelve a correr cad/exportar.sh: todo lo demás se recalcula.
// Las medidas marcadas MEDIR vienen de hojas de vendedores que no coinciden entre sí;
// mide tu pieza con vernier antes de imprimir lo que depende de ellas.

$fn = 48;          // exportar.sh lo sube para los STL finales
holg = 0.3;        // holgura general de impresión (FDM 0.4 mm)

// ───────────────────────── Esfera ─────────────────────────
esfera_d   = 330;              // 30–35 cm
pared      = 4;                // casco PLA, todo perímetros
Re         = esfera_d / 2;     // radio exterior
Ri         = Re - pared;       // radio interior: por aquí ruedan ruedas y ball transfers
circulo_ang = 30;              // radio angular de los 6 círculos naranjas (grados)
rebaje     = 2;                // los círculos son tapas de 2 mm en un asiento de 2 mm
t_int      = 1.8;              // traslape: capa interior (mitad B)
traslape   = 10;               // ancho del traslape de la junta entre mitades
lengueta_n = 6;                // lengüetas de la bayoneta (múltiplo de 3 por simetría)
lengueta_alto = 0.6;           // cuánto sobresale cada lengüeta
lengueta_giro = 7;             // grados que se gira para cerrar
espiga_d   = 1.9;              // agujero para espiga de filamento 1.75 entre gajos
ceja_tapa  = 8;                // ceja que sostiene la tapa de carga (mm de arco)

// ───────────────────────── Motores JGB37-520B (encoder, 319 RPM) ─────────────────────────
caja_d     = 37;     // diámetro de la caja de engranes
caja_L     = 22;     // MEDIR: largo de la caja; 19–29 según la reducción
motor_d    = 35;     // motor 520 + disco del encoder
motor_L    = 50;     // MEDIR: motor + encoder, sin la caja
excentrico = 7;      // el eje de salida va 7 mm fuera del centro de la caja
eje_d      = 6;      // eje D de 6 mm (5.5 entre planos)
eje_L      = 15.5;
buje_d     = 12;     // buje de centrado de la caja
buje_alto  = 6;
caja_pcd   = 31;     // 6 × M3 en un círculo de 31 mm (centrado en la caja)

// ───────────────────────── Ruedas ─────────────────────────
rueda_d       = 65;
rueda_ancho   = 26;
rueda_offset  = 20;    // cara de la caja → plano medio de la rueda: soporte 4 mm + buje + cople hex
hueco_motores = 4;     // separación entre los dos motores, al centro
chaflan_llanta = 2;    // el borde exterior de la llanta (forrada) es redondeado

// Plano medio de cada rueda (distancia al centro en x): los dos motores coaxiales
// llenan el ancho, así que no se elige, sale de las piezas.
a_rueda = rueda_offset + caja_L + motor_L + hueco_motores / 2;
// La rueda es vertical; toca la esfera con su borde exterior.
x_contacto = a_rueda + rueda_ancho / 2 - chaflan_llanta;
z_eje = -(sqrt(Ri * Ri - x_contacto * x_contacto) - rueda_d / 2);
angulo_contacto = asin(x_contacto / Ri);   // inclinación de la pared donde pisa la rueda

// ───────────────────────── Plataforma (melamina) ─────────────────────────
plat_d      = 210;    // 20–22 cm
plat_e      = 15;     // melamina 15 mm
cuna_techo  = 3;      // material del soporte de motor encima de la caja
plat_z_inf  = z_eje + caja_d / 2 + cuna_techo;   // cara de abajo de la plataforma
plat_z_sup  = plat_z_inf + plat_e;               // cara de arriba

// ───────────────────────── Batería y lastre ─────────────────────────
lipo   = [47, 139, 25];   // LiPo 3S 5200 mAh XT60 (Hilldow): x, y, z (va a lo largo de y)
charola_piso = 3;
charola_pared = 4;
lastre_ancho = 34;        // compartimiento de lastre a cada lado de la LiPo (x)
lastre_largo = 84;        // (y)
z_motor_inf = z_eje - motor_d / 2;
lipo_z_sup  = z_motor_inf - 2;          // la LiPo va justo debajo de los motores
lipo_z_inf  = lipo_z_sup - lipo[2];

// ───────────────────────── Ball transfers 1″ ─────────────────────────
bola_d       = 25.4;
bt_y         = 110;    // a 90° de las ruedas, adelante y atrás (fuera de la charola)
bt_brida_d   = 55;     // MEDIR: brida redonda de 3 agujeros (CY-25A típico)
bt_brida_e   = 3;
bt_pcd       = 44;     // MEDIR
bt_cuerpo_d  = 36;     // MEDIR: cuerpo detrás de la brida
bt_cuerpo_L  = 16;     // MEDIR
bt_bola_fuera = 17;    // MEDIR: cuánto sale la bola de la cara de la brida
// centro de la bola: toca el casco por dentro
bt_c_r = Ri - bola_d / 2;
bt_c_z = -sqrt(bt_c_r * bt_c_r - bt_y * bt_y);
bt_inclinacion = asin(bt_y / bt_c_r);    // el ball transfer apunta al centro de la esfera

// ───────────────────────── Poste e imanes ─────────────────────────
tubo_d      = 25;       // tubo PVC conduit 25 mm (el hidráulico de 1/2″ mide 21.3: cámbialo)
iman_d      = 20;       // N42 20 × 5 avellanado M4
iman_e      = 5;
iman_r      = 27;       // radio del círculo de los 4 imanes (poste y cabeza)
hueco_iman_int = 2.5;   // imán del poste ↔ pared interior (2–3 mm)
hueco_iman_ext = 2;     // pared exterior ↔ imán de la cabeza
porta_d     = 74;       // portaimanes del poste
porta_e     = 12;       // grosor al centro (deja lugar a la tuerca M4 bajo cada imán)
// MG996R (cuerpo 40.7 × 19.7 × 42.9 confirmado; orejas y cuerno MEDIR)
servo   = [40.7, 19.7]; // largo, ancho
servo_caja_alto = 36.5; // base → tapa de la caja
servo_alto = 42.9;      // base → punta del estriado
servo_oreja_z = 26.5;   // base → cara de abajo de las orejas
servo_oreja_L = 54.5;
servo_oreja_e = 2.5;
servo_agujeros = [49.5, 10];
servo_eje_x = 40.7 / 2 - 10.2;   // el eje va a 10.2 mm de un extremo
cuerno_d = 25;          // cuerno redondo
cuerno_e = 2.5;
cuerno_sobre = 1.5;     // cuánto queda la cara del cuerno arriba del estriado

porta_z_sup = Ri - hueco_iman_int;           // cara de arriba del portaimanes, al centro
porta_z_inf = porta_z_sup - porta_e;
servo_z_inf = porta_z_inf + cuerno_e - servo_alto - cuerno_sobre;   // cuerno metido 2.5 en el portaimanes
servo_soporte_z = servo_z_inf + servo_oreja_z;   // donde apoyan las orejas
tubo_z_sup  = servo_z_inf - 6;
pie_socket  = 25;                            // cuánto entra el tubo en el pie
tubo_L      = tubo_z_sup - plat_z_sup;       // del plato al tope del tubo (ver echo)

// ───────────────────────── Cabeza ─────────────────────────
cabeza_d   = 0.6 * esfera_d;   // proporción del BB-8 de las películas
Rc         = cabeza_d / 2;
cab_pared  = 2.4;
// Perfil (marco de la cabeza: origen en el polo de la esfera, z = z_robot − Re)
cab_z_ancho = 2;              // altura del punto más ancho
cab_domo_r  = Rc;             // esfera del domo (media esfera truncada)
cab_domo_zc = cab_z_ancho - sqrt(cab_domo_r * cab_domo_r - Rc * Rc);
cab_tapa_r  = 0.45 * Rc;      // la tapa plana de arriba
cab_z_tope  = cab_domo_zc + sqrt(cab_domo_r * cab_domo_r - cab_tapa_r * cab_tapa_r);
cab_r_borde = 0.95 * Rc;      // radio del borde de abajo (se ensancha hacia arriba)
cab_hueco_borde = 4;          // el borde flota a 4 mm del casco
plato_z     = 16;             // cara de abajo del plato interior (el power bank va debajo)
plato_e     = 4;
bolita_d    = 12.7;           // 3 bolas de acero 1/2″ en copas (o mini ball transfers)
bolita_r    = 60;             // radio del círculo de las 3 copas
// Ojo principal: anillo WS2812 16 LED + cámara OV5647 detrás de su centro
ojo_elev    = 38;             // elevación del ojo vista desde el centro del domo
ojo_hueco_d = 40;
ojo_mica_d  = 50;             // mica de acrílico ahumado 3 mm
anillo      = [44.5, 31.8, 1.6];  // diámetro ext., int., grosor del PCB (MEDIR: UNIT dice 45)
camara      = [25, 24, 1];        // OV5647 tipo cámara v1; agujeros M2 21 × 12.5
camara_lente = 8.5;
// Ojo chico (holoproyector): VL53L0X
ojo2_azim   = 28;             // a la derecha del ojo principal
ojo2_z      = 4;              // altura del ojo chico (debajo del plato)
ojo2_inclin = 10;             // el ToF mira 10° hacia abajo
ojo2_d      = 16;
tof         = [25, 13, 1.6];  // MEDIR: GY-530 / CJMCU-530
// Bocina 4 Ω 5 W y power bank
bocina_d    = 40;             // MEDIR: la de UNIT puede ser de 40 o 50 mm
bocina_prof = 20;
bocina_elev = 45;             // atrás y hacia arriba
powerbank   = [26, 97];       // diámetro, largo
pizero      = [65, 30];       // agujeros M2.5 a 58 × 23

// ───────────────────────── Ayudas ─────────────────────────
function norma(v) = sqrt(v * v);
function unitario(v) = v / norma(v);

// Orienta el eje z de los hijos hacia la dirección d.
module apuntar(d) {
    u = unitario(d);
    b = acos(u[2]);
    a = atan2(u[1], u[0]);
    rotate([0, b, a]) children();
}

// Casquete esférico entre dos radios, dentro de un cono de semiángulo ang alrededor de +z.
module casquete(r1, r2, ang) {
    rotate_extrude($fn = $fn * 2)
        polygon(concat([[0, 0]],
            [for (t = [0 : ang / 24 : ang]) [r2 * sin(t), r2 * cos(t)]],
            [for (t = [ang : -ang / 24 : 0]) [r1 * sin(t), r1 * cos(t)]]));
}
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

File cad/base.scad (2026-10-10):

// BB-8 · base motriz (Partes 2 y 6).
//
// La plataforma de melamina va arriba y todo lo pesado cuelga debajo: motores en soportes
// impresos, la LiPo en una charola justo bajo los motores y, a los lados de la LiPo, dos
// compartimentos para 1–1.5 kg de lastre. Los ball transfers van adelante y atrás en
// soportes inclinados que apuntan al centro de la esfera.
//
// Las medidas que salen de la geometría (altura del eje, de la plataforma, inclinación de
// los ball transfers) se calculan en parametros.scad; corre `reportar()` para verlas.
//
// Uso: openscad -D 'parte="soporte_motor"' -o soporte_motor.stl base.scad
//   partes: plataforma (3D)  plataforma_2d (plantilla DXF/SVG 1:1)  soporte_motor
//           soporte_motor_izq  charola  soporte_bt (imprime 2)  panel_carga  vista
// Las piezas sueltas salen ya orientadas para imprimir.

include <parametros.scad>
use <componentes.scad>

parte = "vista";

x_cara = a_rueda - rueda_offset;           // cara de la caja del motor derecho
x_silla = x_cara - caja_L - motor_L + 6;   // donde empieza la silla (el encoder queda libre)
silla_ancho = 52;
ly = lipo[1] + 1;                          // hueco de la LiPo
lx = lipo[0] + 1;
charola_z = lipo_z_inf - charola_piso;     // cara de abajo de la charola

// Posiciones sobre la plataforma (esquina inferior izquierda de cada placa).
POS_PI4   = [-42.5, 34];
POS_UNO   = [5 - 68.6 / 2, -88.7];
POS_L298N = [-71.5, -21.5];
POS_BUCK  = [[28.5, 0.5], [28.5, -21.5]];
POS_MPU   = [-75, 30];
PANEL_AZ  = 225;   // panel de carga: atrás a la izquierda, mirando hacia afuera
PANEL_R   = 86;
alto_separadores = 8;

// ───────────── Agujeros compartidos por la plataforma y las piezas ─────────────
function agujeros_motor(lado) = [for (x = [x_silla + 8, x_cara - 8], s = [-1, 1]) [lado * x, excentrico + s * 22]];
function agujeros_charola() = [for (x = [-15, 15], s = [-1, 1]) [x, s * (ly / 2 - 4)]];
function agujeros_bt(s) = [for (p = [[-14, 86], [14, 86], [0, 98]]) [p[0], s * p[1]]];
function agujeros_pie() = [for (k = [0 : 3]) 22 * [cos(45 + 90 * k), sin(45 + 90 * k)]];
function agujeros_panel() = [for (t = [-18, 18]) (PANEL_R - 9) * [cos(PANEL_AZ), sin(PANEL_AZ)] + t * [-sin(PANEL_AZ), cos(PANEL_AZ)]];
PI4_AG   = [[3.5, 3.5], [61.5, 3.5], [3.5, 52.5], [61.5, 52.5]];
UNO_AG   = [[14, 2.5], [15.3, 50.7], [66.1, 7.6], [66.1, 35.5]];
L298N_AG = [[3, 3], [40, 3], [3, 40], [40, 40]];   // MEDIR

// ───────────── Plataforma ─────────────
module plataforma_2d() {
    // la rueda cruza la plataforma: medio ancho de la muesca a la altura de su cara inferior
    dz = plat_z_inf - z_eje;
    muesca_y = sqrt(rueda_d * rueda_d / 4 - dz * dz) + 4;
    muesca_x = a_rueda - rueda_ancho / 2 - 4;
    difference() {
        circle(d = plat_d, $fn = 180);
        for (l = [-1, 1]) translate([l > 0 ? muesca_x : -muesca_x - plat_d, -muesca_y]) square([plat_d, 2 * muesca_y]);
        for (p = concat(agujeros_motor(1), agujeros_motor(-1), agujeros_charola(),
                        agujeros_bt(1), agujeros_bt(-1), agujeros_pie(), agujeros_panel()))
            translate(p) circle(d = 3.4, $fn = 16);
        for (p = PI4_AG) translate(POS_PI4 + p) circle(d = 2.8, $fn = 16);
        for (p = UNO_AG) translate(POS_UNO + p) circle(d = 3.4, $fn = 16);
        for (p = L298N_AG) translate(POS_L298N + p) circle(d = 3.4, $fn = 16);
        // pasacables (motores, LiPo, ball transfers) y centro marcado
        for (x = [-55, 55]) translate([x, -40]) circle(d = 22, $fn = 48);
        circle(d = 2, $fn = 8);
    }
}

module plataforma() color("burlywood") translate([0, 0, plat_z_inf]) linear_extrude(plat_e) plataforma_2d();

// ───────────── Soporte de motor (derecho; el izquierdo es su espejo) ─────────────
// Silla colgada bajo la plataforma más una placa frontal que se atornilla a la cara de la
// caja con tornillos M3 avellanados (la cabeza no puede salir: la rueda pasa a 3 mm).
module soporte_motor() {
    yc = excentrico;
    alto = plat_z_inf - z_eje;
    difference() {
        union() {
            translate([x_silla, yc - silla_ancho / 2, z_eje]) cube([x_cara - x_silla, silla_ancho, alto]);
            hull() {
                translate([x_cara, yc - silla_ancho / 2, z_eje]) cube([4, silla_ancho, alto]);
                translate([x_cara, yc, z_eje]) rotate([0, 90, 0]) cylinder(d = caja_d + 8, h = 4);
            }
        }
        translate([x_cara - caja_L - 0.5, yc, z_eje]) rotate([0, 90, 0]) cylinder(d = caja_d + 2 * holg, h = caja_L + 0.51);
        translate([x_silla - 1, yc, z_eje]) rotate([0, 90, 0]) cylinder(d = motor_d + 1.5, h = x_cara - caja_L - x_silla + 1.01);
        translate([x_cara - 1, 0, z_eje]) rotate([0, 90, 0]) cylinder(d = buje_d + 1, h = 10);
        for (k = [0 : 5]) translate([x_cara - 1, yc + caja_pcd / 2 * cos(60 * k), z_eje + caja_pcd / 2 * sin(60 * k)])
            rotate([0, 90, 0]) {
                cylinder(d = 3.4, h = 10, $fn = 16);
                translate([0, 0, 1 + 4 - 1.8]) cylinder(d1 = 3.4, d2 = 6.6, h = 1.81, $fn = 16);
            }
        // ranuras para 2 bridas alrededor del motor
        for (x = [x_silla + 12, x_cara - caja_L - 10])
            translate([x, yc - silla_ancho, z_eje + motor_d / 2 + 1]) cube([5, 2 * silla_ancho, 2.2]);
        // tornillos M3 a la plataforma con tuerca atrapada
        for (p = agujeros_motor(1)) translate([p[0], p[1], plat_z_inf - 14]) {
            cylinder(d = 3.4, h = 15, $fn = 16);
            translate([0, 0, 4]) rotate([0, 0, 30]) cylinder(d = 6.4, h = 2.8, $fn = 6);
            translate([0, (p[1] > yc ? 1 : -1) * 6, 4 + 1.4]) cube([5.6, 12, 2.8], center = true);
        }
    }
}

// ───────────── Charola de la LiPo con lastre ─────────────
module charola() {
    ancho = lx + 2 * (lastre_ancho + 2 * charola_pared);
    largo = ly + 2 * charola_pared;
    alto_muro = lipo[2] - 5;
    difference() {
        union() {
            intersection() {
                translate([-ancho / 2, -largo / 2, charola_z]) cube([ancho, largo, charola_piso + alto_muro]);
                sphere(Ri - 3, $fn = 160);
            }
            for (s = [-1, 1]) {
                translate([-25, s > 0 ? ly / 2 : -ly / 2 - charola_pared, charola_z]) cube([50, charola_pared, plat_z_inf - charola_z]);
                translate([-25, s > 0 ? ly / 2 - 10 : -ly / 2, plat_z_inf - 5]) cube([50, 10, 5]);
                // costillas
                for (x = [-25, 21]) translate([x, s > 0 ? ly / 2 - 6 : -ly / 2, charola_z]) cube([4, 6, plat_z_inf - charola_z]);
            }
        }
        translate([-lx / 2, -ly / 2, charola_z + charola_piso]) cube([lx, ly, 200]);
        for (s = [-1, 1]) translate([s > 0 ? lx / 2 + charola_pared : -lx / 2 - charola_pared - lastre_ancho,
                                     -lastre_largo / 2, charola_z + charola_piso]) cube([lastre_ancho, lastre_largo, 200]);
        // ranuras para 2 correas de velcro de 20 mm
        for (y = [-35, 35], s = [-1, 1]) translate([s * (lx / 2 + 1.2) - 1.5, y - 11, charola_z - 1]) cube([3, 22, 10]);
        for (p = agujeros_charola()) translate([p[0], p[1], plat_z_inf - 20]) cylinder(d = 3.4, h = 21, $fn = 16);
        // tuercas M3 por debajo de la pestaña
        for (p = agujeros_charola()) translate([p[0], p[1], plat_z_inf - 5 - 3]) rotate([0, 0, 30]) cylinder(d = 6.4, h = 5.6, $fn = 6);
        // salida del cable de la LiPo
        translate([-8, -ly / 2 - charola_pared - 1, charola_z + charola_piso + 4]) cube([16, charola_pared + 2, 30]);
    }
}

// ───────────── Soporte de ball transfer (s = 1 adelante, −1 atrás) ─────────────
bt_c = [0, bt_y, bt_c_z];
bt_u = unitario(bt_c);
bt_cara = bt_c - (bt_bola_fuera - bola_d / 2) * bt_u;   // cara de la brida
bt_atras = bt_cara - bt_brida_e * bt_u;                  // espalda de la brida

module soporte_bt(s = 1) {
    mirror([0, s > 0 ? 0 : 1, 0]) difference() {
        hull() {
            translate([-24, 80, plat_z_inf - 6]) cube([48, 24, 6]);
            translate(bt_atras) apuntar(bt_u) translate([0, 0, -8]) cylinder(d = bt_brida_d + 2, h = 8);
        }
        // todo lo que va delante de la espalda de la brida (brida, bola) y el cuerpo
        translate(bt_atras) apuntar(bt_u) {
            cylinder(d = bt_brida_d + 30, h = 60);
            translate([0, 0, -bt_cuerpo_L - 1]) cylinder(d = bt_cuerpo_d + 1, h = bt_cuerpo_L + 1.01);
            // tornillos M4 con tuerca por detrás (cavidad para llave de vaso)
            for (k = [0 : 2]) rotate([0, 0, 90 + 120 * k]) translate([bt_pcd / 2, 0, 0]) {
                translate([0, 0, -12]) cylinder(d = 4.5, h = 13, $fn = 16);
                translate([0, 0, -60 - 8]) cylinder(d = 10, h = 60, $fn = 24);
            }
        }
        for (p = agujeros_bt(1)) translate([p[0], p[1], plat_z_inf - 20]) {
            cylinder(d = 3.4, h = 21, $fn = 16);
            translate([0, 0, -46]) cylinder(d = 7, h = 60, $fn = 24);   // cabeza del tornillo por abajo
        }
    }
}
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

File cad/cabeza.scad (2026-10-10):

// BB-8 · cabeza (Parte 5 y 6).
//
// Marco de la cabeza: origen en el polo de arriba de la esfera (z_robot = Re), +y adelante.
// La cabeza no toca el casco más que con 3 bolas de acero de 1/2″ en copas; los 4 imanes
// quedan a `hueco_iman_ext` (2 mm) de la pintura. Todo cuelga de un plato interior:
//   arriba  Pi Zero 2 W, PAM8403, soporte del ojo (anillo WS2812 + OV5647) y de la bocina;
//   abajo   power bank (baja el centro de gravedad), copas, imanes y el VL53L0X del ojo chico.
// El casco baja sobre el plato y se fija con 3 tornillos M3 radiales.
//
// Uso: openscad -D 'parte="casco"' -o cabeza_casco.stl cabeza.scad
//   partes: casco  plato  tapon (imprime 3)  soporte_ojo  soporte_bocina  vista
// Las piezas sueltas salen ya orientadas para imprimir.

include <parametros.scad>
use <componentes.scad>

parte = "vista";

Rd = cab_domo_r;
zc = cab_domo_zc;
r_hueco = Re + cab_hueco_borde;       // esfera del borde de abajo
z_borde = sqrt(r_hueco * r_hueco - cab_r_borde * cab_r_borde) - Re;
plato_sup = plato_z + plato_e;
plato_r = sqrt(pow(Rd - cab_pared, 2) - pow(plato_sup - zc, 2)) - 0.6;
TORNILLOS_AZ = [60, 180, 300];
COPAS_AZ = [90, 210, 330];

// ───────────── Perfil y casco ─────────────
function arco(R, z0, z1, n = 32) = [for (i = [0 : n]) let(z = z0 + (z1 - z0) * i / n) [sqrt(R * R - pow(z - zc, 2)), z]];

module perfil(p) {
    // p = 0: exterior; p = pared: interior
    polygon(concat(
        [[0, z_borde - 20], [cab_r_borde - p, z_borde - 20], [cab_r_borde - p, z_borde]],
        [[Rc - p, cab_z_ancho]],
        arco(Rd - p, cab_z_ancho, cab_z_tope - p),
        [[0, cab_z_tope - p]]));
}

// direcciones (desde el centro del domo) del ojo y de la bocina
n_ojo = [0, cos(ojo_elev), sin(ojo_elev)];
n_boc = [0, -cos(bocina_elev), sin(bocina_elev)];
n_ojo2 = [sin(ojo2_azim) * cos(ojo2_inclin), cos(ojo2_azim) * cos(ojo2_inclin), -sin(ojo2_inclin)];
// radio exterior de la banda a la altura z
function r_banda(z) = cab_r_borde + (Rc - cab_r_borde) * (z - z_borde) / (cab_z_ancho - z_borde);
p_ojo2 = [sin(ojo2_azim) * r_banda(ojo2_z), cos(ojo2_azim) * r_banda(ojo2_z), ojo2_z];

module casco() {
    difference() {
        rotate_extrude($fn = 180) perfil(0);
        rotate_extrude($fn = 180) perfil(cab_pared);
        translate([0, 0, -Re]) sphere(r_hueco, $fn = 360);
        // ojo principal
        translate([0, 0, zc]) apuntar(n_ojo) cylinder(d = ojo_hueco_d, h = Rd + 5, $fn = 96);
        // ojo chico (VL53L0X)
        translate(p_ojo2) apuntar(n_ojo2) cylinder(d = ojo2_d, h = 20, center = true, $fn = 48);
        // rejilla de la bocina: hexágono de agujeros de 3 mm
        translate([0, 0, zc]) apuntar(n_boc) for (i = [-3 : 3], j = [-3 : 3])
            let(x = 6 * (i + j / 2), y = 6 * j * sqrt(3) / 2)
                if (x * x + y * y < pow(bocina_d / 2 - 4, 2)) translate([x, y, Rd - 10]) cylinder(d = 3, h = 20, $fn = 12);
        // antenas (Ø6 y Ø4) en la tapa, hacia atrás
        for (p = [[0, -cab_tapa_r * 0.45, 6], [9, -cab_tapa_r * 0.72, 4]]) translate([p[0], p[1], cab_z_tope - 10]) cylinder(d = p[2], h = 20, $fn = 24);
        // puerto USB del power bank, atrás bajo la antena
        translate([0, -Rc, 2]) cube([13, 30, 7], center = true);
        // tornillos M3 avellanados al plato
        for (a = TORNILLOS_AZ) rotate([0, 0, a]) translate([0, 0, plato_z + plato_e / 2]) rotate([-90, 0, 0]) {
            cylinder(d = 3.4, h = Rc + 5, $fn = 16);
            translate([0, 0, r_banda(plato_z) - 1.9]) cylinder(d1 = 3.4, d2 = 6.8, h = 1.91, $fn = 24);
        }
        // líneas de panel decorativas
        for (z = [cab_z_ancho + 3, cab_z_ancho + 36]) translate([0, 0, z])
            difference() { cylinder(r = Rc + 5, h = 1.2, $fn = 180); cylinder(r = sqrt(Rd * Rd - pow(z - zc, 2)) - 0.6, h = 1.2, $fn = 180); }
    }
}

// ───────────── Plato interior ─────────────
// Dirección de los imanes y de las copas desde el centro de la esfera.
function dir_iman_cab(k) = let(a = 45 + 90 * k, R = Re + hueco_iman_ext) unitario([iman_r * cos(a), iman_r * sin(a), sqrt(R * R - iman_r * iman_r)]);
function dir_copa(a) = let(R = Re + bolita_d / 2) unitario([bolita_r * cos(a), bolita_r * sin(a), sqrt(R * R - bolita_r * bolita_r)]);
// del marco de la esfera al de la cabeza
function cab(p) = p - [0, 0, Re];

lip = sqrt(pow(bolita_d / 2, 2) - pow(0.85 * bolita_d / 2, 2));   // la copa abraza la bola hasta su 85 %

module poste_a_plato(p, d, largo, diam) {
    // cilindro sobre el eje d que arranca en p y sube hasta el plato
    hull() {
        translate(p) apuntar(d) cylinder(d = diam, h = largo);
        translate([p[0], p[1], plato_z]) cylinder(d = diam, h = 1);
    }
}
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

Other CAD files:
cad/stl/esfera_gajo_B_pmp.stl
cad/stl/cabeza_soporte_ojo.stl
cad/stl/esfera_gajo_A_mmp.stl
cad/stl/base_panel_carga.stl
cad/componentes.scad
cad/ensamble.scad
cad/esfera.scad
cad/poste.scad
cad/stl/base_soporte_motor.stl
cad/stl/base_soporte_motor_izq.stl
cad/stl/cabeza_casco.stl
cad/stl/cabeza_plato.stl
cad/stl/cabeza_soporte_bocina.stl
cad/stl/cabeza_tapon.stl
cad/stl/esfera_gajo_A_mpp.stl
cad/stl/esfera_gajo_A_pmm.stl
cad/stl/esfera_gajo_A_pmp.stl
cad/stl/esfera_gajo_A_ppp.stl
cad/stl/esfera_gajo_B_mpm.stl
cad/stl/esfera_tapa_carga.stl

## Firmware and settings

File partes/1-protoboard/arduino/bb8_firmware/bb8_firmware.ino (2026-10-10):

// BB-8 · firmware del Arduino Uno (partes 2, 3 y 6)
//
// Implementa PROTOCOLO.md, sección 1: M, S, H, D, ?, Z, W, I y P (apagado).
// Reflejos cada 10 ms que no esperan a la Pi: rampa, PID con encoders,
// freno por inclinación > 35°, por obstáculo < 250 mm y watchdog de 500 ms.
//
// Librerías: Wire y Servo (vienen con el IDE) y "VL53L0X" de Pololu
// (Gestor de librerías → buscar "VL53L0X Pololu") si USAR_TOF_LOCAL = 1.
//
// Pines (un L298N para los dos motores, jumpers ENA/ENB quitados):
//   D5 ENA, D7 IN1, D8 IN2 → motor izquierdo     D6 ENB, D11 IN3, D12 IN4 → derecho
//   D2/D4 encoder izq C1/C2   D3/D10 encoder der C1/C2   D9 servo del poste
//   A4/A5 I2C (MPU6050 0x68, VL53L0X 0x29)   A2 INT del MPU   A3 corte de la Pi   A0 batería

#include <Wire.h>
#include <Servo.h>
#include <avr/sleep.h>
#include <avr/interrupt.h>

// ============================ CONFIGURACIÓN ================================
#define FW_VERSION "0.1"

#define USAR_TOF_LOCAL   1   // VL53L0X en el I2C del Arduino (partes 1-4). 0 cuando pase a la cabeza.
#define USAR_PID         1   // 0 = lazo abierto (PWM directo), útil si un encoder falla
#define HAY_DIVISOR_BAT  0   // 1 cuando el divisor de la batería esté en A0 (parte 6)

// Si un motor gira al revés de lo esperado, cambia su 0 por 1 (o cruza sus cables).
#define INVERTIR_MOTOR_IZQ 0
#define INVERTIR_MOTOR_DER 0
// Si con "M 80 80" un encoder cuenta hacia abajo, cambia su 0 por 1.
#define INVERTIR_ENC_IZQ   0
#define INVERTIR_ENC_DER   0
// Rumbo: + derecha. El giroscopio Z del MPU6050 montado con el chip arriba da +
// a la izquierda, por eso -1. Si "turn 90" gira a la izquierda, ponlo en 1.
#define SIGNO_GIRO_Z      (-1)
#define SERVO_INVERTIDO    0

// Velocidad: pulsos de encoder en 10 ms a PWM 255. 0.9 m/s × 6464 pulsos/m ≈ 58.
// Mídelo con "python -m calibrar velocidad" y ajústalo.
const float PULSOS_MAX_CICLO = 58.0;
const float KP = 2.0;          // PWM por pulso de error
const float KI = 0.3;
const int   RAMPA = 30;        // máximo cambio de objetivo por ciclo de 10 ms

const float TILT_FRENO = 35.0, TILT_LIBERA = 25.0;
const int   OBSTACULO_MM = 250;
const unsigned long WATCHDOG_MS = 500;
const unsigned long D_VALIDO_MS = 300;    // distancia que llega de la Pi con D
const unsigned long TOF_LOCAL_VALIDO_MS = 150;
const float SERVO_GRADOS_S = 300.0;

// Batería 3S: divisor 10 kΩ (arriba) / 4.7 kΩ (abajo) → 12.6 V se leen como 4.03 V.
const float BAT_FACTOR = (10.0 + 4.7) / 4.7;
const float BAT_BAJA_V = 10.5;      // bandera "bateria": avisar y buscar el cargador
const float BAT_CRITICA_V = 9.9;    // 3.3 V/celda: rechaza M y frena

// Corte de la Pi (parte 6). Nivel en A3 que APAGA la Pi. Con un P-MOSFET de lado
// alto y la compuerta con pull-down de 100 kΩ, el Arduino en reset deja la Pi
// encendida: abrir el puerto serial reinicia el Arduino y no debe apagar la Pi.
#define NIVEL_CORTE_PI HIGH
// ===========================================================================

const uint8_t PIN_ENA = 5, PIN_IN1 = 7, PIN_IN2 = 8;
const uint8_t PIN_ENB = 6, PIN_IN3 = 11, PIN_IN4 = 12;
const uint8_t PIN_SERVO = 9;
const uint8_t PIN_MPU_INT = A2, PIN_CORTE_PI = A3, PIN_BAT = A0;
const uint8_t MPU = 0x68;

#if USAR_TOF_LOCAL
#include <VL53L0X.h>
VL53L0X tof;
bool tofOk = false;
int tofLocalMm = 0;
unsigned long tofLocalT = 0;
#endif

Servo servo;

// --- Encoders en cuadratura ×4 ------------------------------------------------
// C1 en INT0/INT1, C2 en interrupción por cambio de pin (D4 = PCINT20, D10 = PCINT2).
static const int8_t QDEC[16] = {0, -1, 1, 0, 1, 0, 0, -1, -1, 0, 0, 1, 0, 1, -1, 0};
volatile long encIzq = 0, encDer = 0;
volatile uint8_t prevIzq = 0, prevDer = 0;

static inline uint8_t leerIzq() { return (((PIND >> 2) & 1) << 1) | ((PIND >> 4) & 1); }  // D2, D4
static inline uint8_t leerDer() { return (((PIND >> 3) & 1) << 1) | ((PINB >> 2) & 1); }  // D3, D10

void isrIzq() { uint8_t s = leerIzq(); encIzq += QDEC[(prevIzq << 2) | s]; prevIzq = s; }
void isrDer() { uint8_t s = leerDer(); encDer += QDEC[(prevDer << 2) | s]; prevDer = s; }
ISR(PCINT2_vect) { isrIzq(); }   // D4
ISR(PCINT0_vect) { isrDer(); }   // D10
ISR(PCINT1_vect) {}              // A2: solo despierta del reposo profundo

// --- Estado -------------------------------------------------------------------
float objetivo[2] = {0, 0};      // lo que pidió la Pi (−255…255)
float rampa[2] = {0, 0};         // objetivo después de la rampa
float integ[2] = {0, 0};
long encPrevCiclo[2] = {0, 0};
unsigned long ultimoM = 0;

float pitch = 0, roll = 0, inclinacion = 0, rumbo = 0, sesgoGz = 0;
bool imuOk = false;

int distPiMm = 0;
unsigned long distPiT = 0;

float cabeza = 0, cabezaObjetivo = 0;
float bateria = 0;
unsigned long batBajaDesde = 0;

bool fTilt = false, fObstaculo = false, fWatchdog = false, fBatBaja = false, fBatCritica = false;
bool dormido = false;

long apagarEnMs = -1;            // P <s>: cuenta atrás para cortar la Pi
unsigned long apagarDesde = 0;

char linea[64];
uint8_t largo = 0;
bool desborde = false;

// ============================ MOTORES ========================================
// pwm > 0 adelante, < 0 atrás, 0 freno (IN1 = IN2 = HIGH con EN alto: corto del motor).
void motor(uint8_t en, uint8_t a, uint8_t b, int pwm, bool invertir) {
  if (invertir) pwm = -pwm;
  if (pwm > 0) {
    digitalWrite(a, HIGH); digitalWrite(b, LOW); analogWrite(en, pwm);
  } else if (pwm < 0) {
    digitalWrite(a, LOW); digitalWrite(b, HIGH); analogWrite(en, -pwm);
  } else {
    digitalWrite(a, HIGH); digitalWrite(b, HIGH); analogWrite(en, 255);
  }
}

void motores(int izq, int der) {
  motor(PIN_ENA, PIN_IN1, PIN_IN2, izq, INVERTIR_MOTOR_IZQ);
  motor(PIN_ENB, PIN_IN3, PIN_IN4, der, INVERTIR_MOTOR_DER);
}

// Sin PWM ni freno: para dormir (el L298N no tiene modo sleep).
void motoresLibres() {
  analogWrite(PIN_ENA, 0); analogWrite(PIN_ENB, 0);
  digitalWrite(PIN_IN1, LOW); digitalWrite(PIN_IN2, LOW);
  digitalWrite(PIN_IN3, LOW); digitalWrite(PIN_IN4, LOW);
}

void frenar() {
  for (uint8_t i = 0; i < 2; i++) { objetivo[i] = 0; rampa[i] = 0; integ[i] = 0; }
  motores(0, 0);
}

long leerEnc(uint8_t i) {
  noInterrupts();
  long v = i == 0 ? encIzq : encDer;
  interrupts();
  if (i == 0 && INVERTIR_ENC_IZQ) v = -v;
  if (i == 1 && INVERTIR_ENC_DER) v = -v;
  return v;
}

// Un ciclo de 10 ms: rampa → PID → PWM.
void controlRuedas() {
  int salida[2];
  for (uint8_t i = 0; i < 2; i++) {
    float d = objetivo[i] - rampa[i];
    rampa[i] += constrain(d, -RAMPA, RAMPA);

    long e = leerEnc(i);
    float medido = e - encPrevCiclo[i];
    encPrevCiclo[i] = e;

    if (rampa[i] == 0) { integ[i] = 0; salida[i] = 0; continue; }
#if USAR_PID
    float deseado = rampa[i] * PULSOS_MAX_CICLO / 255.0;
    float err = deseado - medido;
    integ[i] = constrain(integ[i] + err, -200, 200);
    float u = rampa[i] + KP * err + KI * integ[i];   // prealimentación + PI
    // Nunca invertir el sentido para frenar: eso lo hacen la rampa y el freno.
    if (rampa[i] > 0) u = constrain(u, 0, 255); else u = constrain(u, -255, 0);
    salida[i] = (int)u;
#else
    salida[i] = (int)rampa[i];
#endif
  }
  motores(salida[0], salida[1]);
}

// ============================ IMU MPU6050 ====================================
void mpuEscribir(uint8_t reg, uint8_t v) {
  Wire.beginTransmission(MPU); Wire.write(reg); Wire.write(v); Wire.endTransmission();
}

uint8_t mpuLeer(uint8_t reg) {
  Wire.beginTransmission(MPU); Wire.write(reg);
  if (Wire.endTransmission(false) != 0) return 0xFF;
  if (Wire.requestFrom(MPU, (uint8_t)1) != 1) return 0xFF;
  return Wire.read();
}

bool mpuMuestras(int16_t *ax, int16_t *ay, int16_t *az, int16_t *gx, int16_t *gy, int16_t *gz) {
  Wire.beginTransmission(MPU); Wire.write(0x3B);
  if (Wire.endTransmission(false) != 0) return false;
  if (Wire.requestFrom(MPU, (uint8_t)14) != 14) return false;
  int16_t v[7];
  for (uint8_t i = 0; i < 7; i++) v[i] = (Wire.read() << 8) | Wire.read();
  *ax = v[0]; *ay = v[1]; *az = v[2]; *gx = v[4]; *gy = v[5]; *gz = v[6];  // v[3] = temperatura
  return true;
}

void mpuConfigurarNormal() {
  mpuEscribir(0x6B, 0x01);   // despierto, reloj del giroscopio X
  mpuEscribir(0x6C, 0x00);   // todos los ejes activos
  mpuEscribir(0x1A, 0x03);   // filtro paso bajo 44 Hz
  mpuEscribir(0x1B, 0x08);   // giroscopio ±500 °/s → 65.5 LSB/(°/s)
  mpuEscribir(0x1C, 0x08);   // acelerómetro ±4 g → 8192 LSB/g
  mpuEscribir(0x38, 0x00);   // sin interrupciones
}

bool iniciarImu() {
  if (mpuLeer(0x75) == 0xFF) return false;   // WHO_AM_I: 0x68 en el original, 0x70/0x72 en clones
  mpuConfigurarNormal();
  delay(50);
  // Sesgo del giroscopio Z: el robot tiene que estar quieto el primer segundo.
  long suma = 0; int n = 0;
  int16_t ax, ay, az, gx, gy, gz;
  for (int i = 0; i < 200; i++) {
    if (mpuMuestras(&ax, &ay, &az, &gx, &gy, &gz)) { suma += gz; n++; }
    delay(5);
  }
  if (n < 100) return false;
  sesgoGz = (float)suma / n;
  return true;
}

void leerImu(float dt) {
  int16_t ax, ay, az, gx, gy, gz;
  if (!imuOk || !mpuMuestras(&ax, &ay, &az, &gx, &gy, &gz)) { imuOk = false; return; }
  const float G = 65.5;
  float accPitch = atan2(-(float)ax, sqrt((float)ay * ay + (float)az * az)) * RAD_TO_DEG;
  float accRoll = atan2((float)ay, (float)az) * RAD_TO_DEG;
  // Filtro complementario: giroscopio a corto plazo, acelerómetro a largo plazo.
  pitch = 0.98 * (pitch + gy / G * dt) + 0.02 * accPitch;
  roll = 0.98 * (roll + gx / G * dt) + 0.02 * accRoll;
  inclinacion = max(fabs(pitch), fabs(roll));
  float gzDps = (gz - sesgoGz) / G;
  if (fabs(gzDps) > 0.3) rumbo += SIGNO_GIRO_Z * gzDps * dt;   // zona muerta contra la deriva
}

// ============================ DISTANCIA ======================================
#if USAR_TOF_LOCAL
void iniciarTof() {
  tof.setTimeout(50);
  tofOk = tof.init();
  if (tofOk) {
    tof.setMeasurementTimingBudget(33000);
    tof.startContinuous();
  }
}

// Sin bloquear: solo lee si ya hay medida (la función de la librería espera hasta 33 ms).
void leerTof(unsigned long ahora) {
  if (!tofOk) return;
  if ((tof.readReg(VL53L0X::RESULT_INTERRUPT_STATUS) & 0x07) == 0) return;
  uint16_t mm = tof.readReg16Bit(VL53L0X::RESULT_RANGE_STATUS + 10);
  tof.writeReg(VL53L0X::SYSTEM_INTERRUPT_CLEAR, 0x01);
  tofLocalMm = (mm > 0 && mm < 2000) ? mm : 0;   // 8190 = nada a la vista
  tofLocalT = ahora;
}
#endif

// Distancia al frente que usa el freno: gana la local; si no, la que mandó la Pi.
int distanciaMm(unsigned long ahora) {
#if USAR_TOF_LOCAL
  if (tofOk && ahora - tofLocalT < TOF_LOCAL_VALIDO_MS) return tofLocalMm;
#endif
  if (distPiMm > 0 && ahora - distPiT < D_VALIDO_MS) return distPiMm;
  return 0;
}

// ============================ BATERÍA ========================================
void leerBateria(unsigned long ahora) {
#if HAY_DIVISOR_BAT
  float v = analogRead(PIN_BAT) * (5.0 / 1023.0) * BAT_FACTOR;
  bateria = bateria == 0 ? v : 0.95 * bateria + 0.05 * v;
  // 5 s seguidos por debajo, para que un arranque de motor no dispare la bandera.
  if (bateria < BAT_BAJA_V) {
    if (batBajaDesde == 0) batBajaDesde = ahora | 1;
    if (ahora - batBajaDesde > 5000) {
      fBatBaja = true;
      if (bateria < BAT_CRITICA_V) fBatCritica = true;
    }
  } else if (bateria > BAT_BAJA_V + 0.3) {
    batBajaDesde = 0; fBatBaja = false; fBatCritica = false;
  }
#else
  (void)ahora;
  bateria = 0;   // 0.00 = no se mide (fuente de pared)
#endif
}

// ============================ SERVO ==========================================
void moverServo(float dt) {
  float paso = SERVO_GRADOS_S * dt;
  cabeza += constrain(cabezaObjetivo - cabeza, -paso, paso);
  if (!dormido) {
    float g = SERVO_INVERTIDO ? -cabeza : cabeza;
    servo.writeMicroseconds(1500 + (int)(g * 1000.0 / 90.0));   // ±90° ≈ 500…2500 µs
  }
}

// ============================ REPOSO PROFUNDO ================================
// La Pi ya se apagó (P <s>): cortar su alimentación y dormir hasta que la IMU
// detecte movimiento. Al despertar se reconecta la Pi y el Arduino se reinicia
// cuando ella abre el puerto serial.
void reposoProfundo() {
  frenar();
  motoresLibres();
  servo.detach();
#if USAR_TOF_LOCAL
  if (tofOk) tof.stopContinuous();
#endif
  digitalWrite(PIN_CORTE_PI, NIVEL_CORTE_PI);
  Serial.flush();

  if (imuOk) {
    mpuEscribir(0x1C, 0x09);   // ±4 g con filtro paso alto de 5 Hz (requisito de la detección)
    mpuEscribir(0x1F, 20);     // umbral de movimiento: 20 × 2 mg = 40 mg
    mpuEscribir(0x20, 1);      // duración 1 ms
    mpuEscribir(0x37, 0x20);   // INT activo alto y retenido hasta leer INT_STATUS
    mpuEscribir(0x38, 0x40);   // interrupción de movimiento
    mpuEscribir(0x6C, 0x47);   // ciclo a 5 Hz, giroscopios apagados
    mpuEscribir(0x6B, 0x20);   // modo ciclo: ~10 µA
    mpuLeer(0x3A);             // limpiar
  }

  // Sin IMU, A2 con pull-up nunca cambia: duerme hasta que se apague el interruptor.
  pinMode(PIN_MPU_INT, imuOk ? INPUT : INPUT_PULLUP);
  PCMSK1 |= _BV(PCINT10);      // A2
  PCIFR |= _BV(PCIF1);
  PCICR |= _BV(PCIE1);
  ADCSRA &= ~_BV(ADEN);

  for (;;) {
    set_sleep_mode(SLEEP_MODE_PWR_DOWN);
    noInterrupts();
    sleep_enable();
    interrupts();
    sleep_cpu();               // aquí se queda hasta el cambio en A2
    sleep_disable();
    delay(5);
    if (imuOk && digitalRead(PIN_MPU_INT) == HIGH) break;   // movimiento de verdad, no ruido
  }

  PCICR &= ~_BV(PCIE1);
  PCMSK1 &= ~_BV(PCINT10);
  ADCSRA |= _BV(ADEN);
  if (imuOk) { mpuLeer(0x3A); mpuConfigurarNormal(); }
#if USAR_TOF_LOCAL
  if (tofOk) tof.startContinuous();
#endif
  digitalWrite(PIN_CORTE_PI, !NIVEL_CORTE_PI);   // la Pi arranca (~25 s)
  servo.attach(PIN_SERVO, 500, 2500);
  dormido = false;
  apagarEnMs = -1;
  ultimoM = millis();
}

// ============================ ÓRDENES ========================================
bool entero(const char *s, long *v) {
  if (!s || !*s) return false;
  char *fin;
  *v = strtol(s, &fin, 10);
  return *fin == '\0';
}

void responderEstado(unsigned long ahora) {
  Serial.print(F("OK V=")); Serial.print(bateria, 2);
  Serial.print(F(" T=")); Serial.print(inclinacion, 1);
  Serial.print(F(" Y=")); Serial.print(rumbo, 1);
  Serial.print(F(" E=")); Serial.print(leerEnc(0)); Serial.print(','); Serial.print(leerEnc(1));
  Serial.print(F(" H=")); Serial.print((int)round(cabeza));
  Serial.print(F(" D=")); Serial.print(distanciaMm(ahora));
  Serial.print(F(" F="));
  bool alguna = false;
  const char *nombres[] = {"bateria", "imu", "obstacle", "sleep", "tilt", "watchdog"};
  bool activas[] = {fBatBaja, !imuOk, fObstaculo, dormido, fTilt, fWatchdog};
  for (uint8_t i = 0; i < 6; i++) {
    if (!activas[i]) continue;
    if (alguna) Serial.print(',');
    Serial.print(nombres[i]);
    alguna = true;
  }
  if (!alguna) Serial.print('-');
  Serial.println();
}

void ejecutar(char *s) {
  unsigned long ahora = millis();
  char *tok[4];
  uint8_t n = 0;
  for (char *t = strtok(s, " "); t && n < 4; t = strtok(NULL, " ")) tok[n++] = t;
  if (n == 0 || strlen(tok[0]) != 1) { Serial.println(F("ERR syntax")); return; }
  char op = tok[0][0];
  long a = 0, b = 0;

  switch (op) {
    case 'M': {
      if (n != 3 || !entero(tok[1], &a) || !entero(tok[2], &b)) break;
      if (a < -255 || a > 255 || b < -255 || b > 255) { Serial.println(F("ERR range")); return; }
      if (dormido) { Serial.println(F("ERR sleep")); return; }
      if (fTilt) { Serial.println(F("ERR tilt")); return; }
      if (fBatCritica) { frenar(); Serial.println(F("ERR bateria")); return; }
      int d = distanciaMm(ahora);
      if (a + b > 0 && d > 0 && d < OBSTACULO_MM) { frenar(); Serial.println(F("ERR obstacle")); return; }
      objetivo[0] = a; objetivo[1] = b;
      ultimoM = ahora;
      fWatchdog = false;
      Serial.println(F("OK"));
      return;
    }
    case 'S':
      if (n != 1) break;
      frenar();
      Serial.println(F("OK"));
      return;
    case 'H':
      if (n != 2 || !entero(tok[1], &a)) break;
      if (a < -90 || a > 90) { Serial.println(F("ERR range")); return; }
      if (dormido) { Serial.println(F("ERR sleep")); return; }
      cabezaObjetivo = a;
      Serial.println(F("OK"));
      return;
    case 'D':
      if (n != 2 || !entero(tok[1], &a)) break;
      if (a < 0 || a > 4000) { Serial.println(F("ERR range")); return; }
      distPiMm = a; distPiT = ahora;
      Serial.println(F("OK"));
      return;
    case '?':
      if (n != 1) break;
      responderEstado(ahora);
      return;
    case 'Z':
      if (n != 1) break;
      frenar();
      motoresLibres();
      servo.detach();          // ~100 mA → ~5 mA
      dormido = true;
      Serial.println(F("OK"));
      return;
    case 'W':
      if (n != 1) break;
      if (dormido) {
        servo.attach(PIN_SERVO, 500, 2500);
        motores(0, 0);
      }
      dormido = false;
      Serial.println(F("OK"));
      return;
    case 'I':
      if (n != 1) break;
      Serial.println(F("OK BB8 fw=" FW_VERSION));
      return;
    case 'P':   // P <s>: la Pi se apaga; cortarle la corriente en s segundos y dormir. P 0 cancela.
      if (n != 2 || !entero(tok[1], &a)) break;
      if (a != 0 && (a < 5 || a > 120)) { Serial.println(F("ERR range")); return; }
      if (a == 0) { apagarEnMs = -1; Serial.println(F("OK")); return; }
      frenar();
      apagarEnMs = a * 1000L;
      apagarDesde = ahora;
      Serial.println(F("OK"));
      return;
  }
  Serial.println(F("ERR syntax"));
}

void leerSerial() {
  while (Serial.available()) {
    char c = Serial.read();
    if (c == '\r') continue;
    if (c == '\n') {
      if (desborde) Serial.println(F("ERR syntax"));
      else if (largo > 0) { linea[largo] = '\0'; ejecutar(linea); }
      else Serial.println(F("ERR syntax"));
      largo = 0; desborde = false;
    } else if (largo < sizeof(linea) - 1) {
      linea[largo++] = c;
    } else {
      desborde = true;
    }
  }
}

// ============================ CICLO ==========================================
void setup() {
  pinMode(PIN_CORTE_PI, OUTPUT);
  digitalWrite(PIN_CORTE_PI, !NIVEL_CORTE_PI);   // la Pi sigue encendida
  pinMode(PIN_ENA, OUTPUT); pinMode(PIN_IN1, OUTPUT); pinMode(PIN_IN2, OUTPUT);
  pinMode(PIN_ENB, OUTPUT); pinMode(PIN_IN3, OUTPUT); pinMode(PIN_IN4, OUTPUT);
  motores(0, 0);

  pinMode(2, INPUT_PULLUP); pinMode(4, INPUT_PULLUP);
  pinMode(3, INPUT_PULLUP); pinMode(10, INPUT_PULLUP);
  prevIzq = leerIzq(); prevDer = leerDer();
  attachInterrupt(digitalPinToInterrupt(2), isrIzq, CHANGE);
  attachInterrupt(digitalPinToInterrupt(3), isrDer, CHANGE);
  PCMSK2 |= _BV(PCINT20);   // D4
  PCMSK0 |= _BV(PCINT2);    // D10
  PCICR |= _BV(PCIE2) | _BV(PCIE0);

  Serial.begin(115200);
  Wire.begin();
  Wire.setClock(400000);
  Wire.setWireTimeout(3000, true);   // un bus I2C colgado por ruido de motores no congela el lazo

  servo.attach(PIN_SERVO, 500, 2500);
  servo.writeMicroseconds(1500);

  imuOk = iniciarImu();
#if USAR_TOF_LOCAL
  iniciarTof();
#endif
  leerBateria(millis());
  ultimoM = millis();
}

void loop() {
  static unsigned long previo = micros();
  leerSerial();

  unsigned long t = micros();
  if (t - previo < 10000) return;
  float dt = (t - previo) * 1e-6;
  previo = t;
  unsigned long ahora = millis();

  leerImu(dt);
#if USAR_TOF_LOCAL
  leerTof(ahora);
#endif
  leerBateria(ahora);

  // Reflejo 1: inclinación (con histéresis).
  if (inclinacion > TILT_FRENO) {
    if (!fTilt) frenar();
    fTilt = true;
    objetivo[0] = objetivo[1] = 0;
  } else if (inclinacion < TILT_LIBERA) {
    fTilt = false;
  }

  // Reflejo 2: obstáculo al frente mientras avanza.
  int d = distanciaMm(ahora);
  if (d > 0 && d < OBSTACULO_MM) {
    if (objetivo[0] + objetivo[1] > 0 || rampa[0] + rampa[1] > 0) frenar();
    fObstaculo = true;
  } else {
    fObstaculo = false;
  }

  // Reflejo 3: watchdog. Solo M lo alimenta.
  if ((objetivo[0] != 0 || objetivo[1] != 0) && ahora - ultimoM > WATCHDOG_MS) {
    frenar();
    fWatchdog = true;
  }

  // Reflejo 4: batería crítica.
  if (fBatCritica && (objetivo[0] != 0 || objetivo[1] != 0)) frenar();

  if (!dormido) controlRuedas();
  moverServo(dt);

  if (apagarEnMs >= 0 && (long)(ahora - apagarDesde) >= apagarEnMs) {
    reposoProfundo();
    previo = micros();
  }
}

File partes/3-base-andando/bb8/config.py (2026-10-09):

"""Constantes del robot y direcciones de los servicios.

Todo lo que se calibra está aquí. Las direcciones se pueden cambiar con
variables de entorno sin tocar el código.
"""
import math
import os

# --- Direcciones -----------------------------------------------------------
# Puerto serial del Arduino. En el dummy: socket://127.0.0.1:5555
SERIAL_URL = os.environ.get("BB8_SERIAL", "/dev/ttyACM0")
SERIAL_BAUD = 115200
# Cabeza (Pi Zero 2 W). En el dummy: http://127.0.0.1:8080
HEAD_URL = os.environ.get("BB8_HEAD_URL", "http://bb8-head.local:8080")
# Servicio de movimiento (solo localhost)
MOTION_HOST = os.environ.get("BB8_MOTION_HOST", "127.0.0.1")
MOTION_PORT = int(os.environ.get("BB8_MOTION_PORT", "8770"))
MOTION_URL = os.environ.get("BB8_MOTION_URL", f"http://{MOTION_HOST}:{MOTION_PORT}")
# Servidor MCP
MCP_HOST = os.environ.get("BB8_MCP_HOST", "127.0.0.1")
MCP_PORT = int(os.environ.get("BB8_MCP_PORT", "8765"))

# --- Mecánica (calibrar en la Parte 3) -------------------------------------
WHEEL_DIAMETER_M = 0.065
# JGB37-520 319 RPM: 11 pulsos/vuelta del motor × ~1:30 × 4 flancos. Verificar
# girando la rueda 10 vueltas a mano y leyendo E con "?".
TICKS_PER_REV = 1320
# >1 si la rueda patina dentro de la esfera (avanza menos de lo que cuenta).
SLIP_FACTOR = 1.0
TICKS_PER_M = TICKS_PER_REV / (math.pi * WHEEL_DIAMETER_M) * SLIP_FACTOR
TRACK_WIDTH_M = 0.17  # distancia entre ruedas
# Velocidad a PWM 255. 319 RPM × π × 0.065 / 60 = 1.08 m/s a 12 V; el L298N
# deja ~10 V al motor, así que ~0.9 m/s.
V_MAX_MPS = 0.9

# --- Límites de seguridad (un solo sitio) ----------------------------------
PWM_CRUISE = 140        # ~55 % → ~0.5 m/s
PWM_MIN = 45            # por debajo los motores no vencen la fricción
PWM_TURN = 90
PWM_TURN_MIN = 40
PWM_MANUAL_MAX = 150
MOVE_MAX_M = 2.0
TURN_MAX_DEG = 360.0
HEAD_MAX_DEG = 90
ORDER_MAX_S = 5.0       # duración máxima de una orden
MANUAL_HOLD_S = 1.0     # el mando manda si tocó algo en el último segundo
GAMEPAD_DEADZONE = 10   # en escala 0..255

# --- Ciclos ----------------------------------------------------------------
POLL_S = 0.05           # sondeo de estado "?" (50 ms)
KEEPALIVE_S = 0.1       # reenvío de M mientras hay movimiento
TOF_POLL_S = 0.1        # lectura del ToF de la cabeza
TOF_FORWARD_MAX_HEAD_DEG = 15  # más allá, el ToF no mira al camino
OBSTACLE_MM = 250

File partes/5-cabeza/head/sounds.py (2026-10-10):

"""Pitidos de droide generados con matemática pura (sin archivos WAV ni numpy).

Cada sonido es una lista de sílabas: un barrido de frecuencia con vibrato y un timbre.
Cada vez que suena cambia un poco el tono y el tempo (hay 4 variantes en caché), para
que no parezca grabado. Un texto cualquiera da un balbuceo propio: mismo texto, mismos
pitidos, con la entonación de su puntuación (¿…? sube al final, ¡…! va más agudo).

Escuchar en el PC:
    python -m head.sounds                    # todos, con su descripción
    python -m head.sounds feliz curioso      # algunos
    python -m head.sounds --texto "¿Quién anda ahí?"
    python -m head.sounds --guardar sonidos/ # un WAV por sonido
    python -m head.sounds --html sonidos.html  # página para oírlos en el navegador
"""
from __future__ import annotations

import argparse
import base64
import functools
import io
import math
import os
import platform
import random
import re
import shutil
import subprocess
import sys
import tempfile
import time
import wave
from array import array
from typing import NamedTuple

RATE = 22050
TAU = 2 * math.pi


class Silaba(NamedTuple):
    f0: float               # Hz al empezar; 0 = silencio
    f1: float               # Hz al terminar
    dur: float              # segundos
    vib: float = 0.0        # vibrato: fracción de la frecuencia (0.05 = ±5 %)
    vib_hz: float = 0.0     # vibrato: oscilaciones por segundo
    timbre: str = "suave"   # suave, brillante o zumbido
    vol: float = 1.0


def S(f0, f1, dur, vib=0.0, vib_hz=0.0, timbre="suave", vol=1.0) -> Silaba:
    return Silaba(f0, f1, dur, vib, vib_hz, timbre, vol)


def P(dur: float) -> Silaba:
    return Silaba(0, 0, dur)


def _trino(fa: float, fb: float, n: int, dur: float = 0.035, **kw) -> list[Silaba]:
    return [S(fa if i % 2 == 0 else fb, fb if i % 2 == 0 else fa, dur, **kw) for i in range(n)]


# Armónicos (multiplicador, peso) por timbre.
TIMBRES = {
    "suave": ((1, 0.8), (2, 0.2)),
    "brillante": ((1, 0.6), (2, 0.25), (3, 0.15)),
    "zumbido": ((1, 0.55), (3, 0.25), (5, 0.12), (7, 0.08)),   # casi cuadrada: gruñón
}

# nombre → (cómo suena, sílabas). El nombre es también la emoción (head.personalidad).
SONIDOS: dict[str, tuple[str, list[Silaba]]] = {
    "feliz": ("chirridos que suben, saltarines", [
        S(900, 1500, 0.08), S(1500, 2200, 0.07, 0.03, 18), P(0.03),
        S(1200, 1900, 0.09), S(1900, 2500, 0.06, timbre="brillante")]),
    "emocionado": ("trino rápido y agudo que se dispara hacia arriba", [
        *_trino(1600, 2300, 6, 0.03, timbre="brillante"), P(0.02),
        S(1200, 2900, 0.22, 0.05, 22, "brillante")]),
    "saludo": ("bi-du-íiip: dos notas y una larga que sube ondulando", [
        S(1100, 1100, 0.06), P(0.03), S(1500, 1300, 0.06), P(0.04),
        S(900, 1900, 0.30, 0.04, 9)]),
    "curioso": ("sube y baja como preguntándose algo", [
        S(700, 1100, 0.09), S(1100, 850, 0.08), P(0.04), S(850, 1700, 0.20, 0.03, 7)]),
    "pregunta": ("nota plana y luego una subida: ¿eh?", [
        S(700, 700, 0.10), P(0.02), S(800, 1600, 0.18)]),
    "pensando": ("blips suaves sin prisa, tecleando por dentro", [
        S(950, 950, 0.04, vol=0.6), P(0.07), S(1150, 1150, 0.04, vol=0.6), P(0.05),
        S(1050, 1050, 0.04, vol=0.6), P(0.09), S(1250, 1200, 0.05, vol=0.6), P(0.06),
        S(1000, 1080, 0.06, vol=0.6)]),
    "si": ("dos blips que suben: ¡ajá!", [
        S(1000, 1050, 0.06), P(0.03), S(1400, 1700, 0.09)]),
    "no": ("dos notas que bajan, un poco gruñonas", [
        S(900, 750, 0.09, timbre="zumbido", vol=0.7), P(0.04),
        S(700, 450, 0.16, timbre="zumbido", vol=0.7)]),
    "alerta": ("tres pitidos secos y agudos", [
        S(1800, 1800, 0.06, timbre="brillante"), P(0.04)] * 3),
    "asustado": ("grito agudo que tiembla y un trino nervioso", [
        S(2400, 1400, 0.12, 0.08, 30, "brillante"), S(1500, 2800, 0.18, 0.10, 26, "brillante"),
        P(0.02), *_trino(2600, 2000, 6, 0.025)]),
    "triste": ("dos notas largas que caen, con temblor lento", [
        S(900, 500, 0.30, 0.03, 5), P(0.05), S(600, 320, 0.45, 0.04, 4)]),
    "error": ("zumbido grave: algo salió mal", [
        S(420, 420, 0.12, timbre="zumbido"), P(0.05), S(320, 240, 0.28, 0.02, 12, "zumbido")]),
    "bostezo": ("sube despacio y cae largo: tengo sueño", [
        S(450, 850, 0.35, vol=0.7), S(850, 330, 0.65, 0.02, 3, vol=0.6)]),
    "despertar": ("barrido de grave a agudo y dos chirridos: sistemas en línea", [
        S(300, 1800, 0.35, 0.01, 6), P(0.04), S(1500, 2000, 0.05), P(0.02), S(1800, 2300, 0.06)]),
    "risa": ("ji-ji-ji electrónico que baja", [
        *(s for i in range(5) for s in (S(1900 - 120 * i, 1500 - 120 * i, 0.05), P(0.025)))]),
}


# ── Síntesis ─────────────────────────────────────────────────────────────────

def _render(silabas: list[Silaba], volume: float, tono: float = 1.0, tempo: float = 1.0) -> array:
    out = array("h")
    sin = math.sin
    phase = 0.0
    for s in silabas:
        n = int(RATE * s.dur / tempo)
        if s.f0 <= 0:
            out.extend([0] * n)
            continue
        f0, f1 = s.f0 * tono, s.f1 * tono
        ratio = f1 / f0
        harm = TIMBRES[s.timbre]
        amp = volume * s.vol * 32767
        ataque, cola = max(1, int(0.004 * RATE)), max(1, int(0.012 * RATE))
        wv = TAU * s.vib_hz / RATE
        for i in range(n):
            x = i / n
            f = f0 * ratio ** x     # barrido exponencial: suena parejo al oído
            if s.vib:
                f *= 1 + s.vib * sin(wv * i)
            phase += TAU * f / RATE
            env = min(1.0, i / ataque, (n - i) / cola)
            v = 0.0
            for k, w in harm:
                v += w * sin(k * phase)
            out.append(int(amp * env * v))
    return out


def _wav(muestras: array) -> bytes:
    buf = io.BytesIO()
    with wave.open(buf, "wb") as w:
        w.setnchannels(1)
        w.setsampwidth(2)
        w.setframerate(RATE)
        if sys.byteorder == "big":
            muestras = array("h", muestras)
            muestras.byteswap()
        w.writeframes(muestras.tobytes())
    return buf.getvalue()
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

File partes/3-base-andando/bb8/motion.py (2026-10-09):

"""Servicio de movimiento: único dueño del serial y árbitro mando/LLM.

Traduce move(1.0) y turn(90) en órdenes M con lazo cerrado sobre encoders y
giroscopio, sondea el estado del Arduino cada 50 ms y reenvía el ToF de la
cabeza como D <mm>. Ver PROTOCOLO.md, secciones 1 y 2.
"""
from __future__ import annotations

import asyncio
import logging
import math
import time

import httpx

from . import config as C
from . import protocol as P
from .serial_link import SerialLink

log = logging.getLogger("bb8.motion")


def _clamp(v: float, lo: float, hi: float) -> float:
    return max(lo, min(hi, v))


class MotionService:
    def __init__(self, link: SerialLink, head_url: str = C.HEAD_URL):
        self.link = link
        self.head_url = head_url.rstrip("/")
        self.status = P.Status()
        self.status_t = 0.0
        self.tof_mm = 0
        self.asleep = False
        self.x_m = 0.0
        self.y_m = 0.0
        self._prev_enc: tuple[int, int] | None = None
        self._tick = asyncio.Event()
        self._motion_lock = asyncio.Lock()
        self._cancel_gen = 0
        self._last_manual = -math.inf
        self._tasks: list[asyncio.Task] = []
        self._http: httpx.AsyncClient | None = None
        self._head_ok = True

    # --- arranque y lazos de fondo -------------------------------------------

    async def start(self) -> None:
        await asyncio.to_thread(self.link.open)
        await self._send(P.cmd_head(0))
        self._http = httpx.AsyncClient(timeout=0.3)
        self._tasks = [asyncio.create_task(self._poll_loop()),
                       asyncio.create_task(self._tof_loop())]
        await self._wait_status()

    async def close(self) -> None:
        for t in self._tasks:
            t.cancel()
        try:
            await self._send(P.CMD_STOP)
        except Exception:
            pass
        if self._http:
            await self._http.aclose()
        self.link.close()

    async def _send(self, line: str) -> str:
        return await asyncio.to_thread(self.link.send, line)

    async def _poll_loop(self) -> None:
        while True:
            try:
                st = P.parse_status(await self._send(P.CMD_STATUS))
                self._update_odometry(st)
                self.status, self.status_t = st, time.monotonic()
                tick, self._tick = self._tick, asyncio.Event()
                tick.set()
            except Exception as e:
                log.warning("Sondeo de estado falló: %s", e)
            await asyncio.sleep(C.POLL_S)

    async def _wait_status(self) -> P.Status:
        try:
            await asyncio.wait_for(self._tick.wait(), timeout=0.5)
        except asyncio.TimeoutError:
            log.warning("Sin estado nuevo del Arduino en 500 ms")
        return self.status

    def _update_odometry(self, st: P.Status) -> None:
        enc = (st.enc_left, st.enc_right)
        if self._prev_enc is not None:
            d = ((enc[0] - self._prev_enc[0]) + (enc[1] - self._prev_enc[1])) / 2 / C.TICKS_PER_M
            yaw = math.radians(st.yaw_deg)
            self.x_m += d * math.cos(yaw)
            self.y_m += d * math.sin(yaw)  # y positivo a la derecha, como el rumbo
        self._prev_enc = enc
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

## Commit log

2026-10-09 Organizar el repo por partes y agregar la wiki
    - partes/1..6: el código de cada parte del plan (firmware y pruebas del
    Arduino, servicio de movimiento y calibración, MCP y agente de voz,
    cabeza, energía), cada una con su README
    - simulador/: robot dummy y prueba de punta a punta (python -m dummy.probar)
    - pyproject.toml mapea cada paquete a su carpeta (pip install -e .)
    - El servidor MCP pasa a ser el paquete bb8_mcp y calibrar/probar dejan tools/
    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
2026-10-09 Agregar CLAUDE.md, skills del proyecto y el MCP bb8 para Claude Code
    - CLAUDE.md: mapa del repo, comandos, reglas de seguridad y del protocolo
    - .claude/skills: probar-dummy, cambiar-protocolo, agregar-herramienta-mcp,
    firmware-arduino, manejar-bb8
    - .mcp.json registra el servidor bb8 (dummy en 127.0.0.1:8765) y
    .claude/settings.json lo habilita
    - Wiki y README mencionan la configuración
    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
2026-10-09 Agregar visor 2D del simulador en el navegador (/sim)
    La cabeza simulada sirve /sim: una vista desde arriba de la habitación que
    pregunta /sim/mundo 10 veces por segundo y dibuja el robot, la cabeza, el
    rayo del ToF, el ojo con su patrón, la estela y lo último que dijo. Al lado
    muestra pose, PWM, frenos activos y la cámara. /sim/mundo ahora incluye PWM,
    banderas, rayo del ToF, ojo y voz. Wiki, README y skill actualizados.
    Claude-Session: https://claude.ai/code/session_018eUHpDCBQQ1XSc2dXxM4Vf
2026-10-09 Cotizar las compras pendientes en tiendas de México
    Actualiza wiki/Materiales.md con precios del 9 oct 2026 (UNIT, Amazon MX,
    Mercado Libre, Steren) y dos carritos: lo que se puede pedir ya (Partes 2,
    4 y 5) y lo de la Parte 6. Corrige que la llanta de 65 mm de UNIT con
    accesorios sí sirve para el JGB37 y que la Zero usa cable de cámara 15 → 22.
    Claude-Session: https://claude.ai/code/session_01Uc7zHstDQxjh41GnGpXrtg
2026-10-09 Agregar CI (firmware + dummy) y el firmware en Wokwi
    - .github/workflows/ci.yml: compila bb8_firmware y las pruebas p1…p5 para Uno y
    Nano con arduino-cli (sube el .hex/.elf como artefacto) y corre
    python -m dummy.probar contra el dummy en cada push y PR.
    - partes/1-protoboard/wokwi: diagram.json, wokwi.toml y libraries.txt con el
    MPU6050, el servo, dos encoders KY-040, LEDs en lugar del L298N, el corte de
    la Pi y un potenciómetro como batería, más un README de qué probar.
    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
2026-10-09 Agregar banco de sonidos y personalidad de BB-8
    - head/sounds.py: sintetizador de pitidos con 15 emociones (sílabas con barrido,
    vibrato y timbre), 4 variantes por sonido y balbuceo por frase según la
    puntuación. Vista previa en el PC: python -m head.sounds (sonar, --guardar WAV,
    --html página).
    - head/personalidad.py: emoción → pitido + color de ojo, frases cortas por
    situación sin repetir y la sección de personalidad del system prompt.
    - bb8_mcp: herramienta express(emocion) y say con los 15 sonidos; las
    instrucciones suman la personalidad.
    - voz: frases fijas desde personalidad y pitidos despertar, bostezo y error.
    - dummy.probar: 19 comprobaciones (express válida e in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
    [backends_sim.py, personalidad.py, server.py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]
2026-10-09 Wake word "oye BB-8": pipeline de entrenamiento y carga automática
    - partes/4-agente-movimiento/wakeword/: entrena un modelo de openWakeWord con voces de
    Piper en español (positivas "oye bi bi eit" y negativas parecidas), eco, ruido y los
    negativos ACAV100M de la receta oficial. entrenar.py (datos, muestras, aumentar,
    modelo), cuaderno para Colab, probar.py para elegir el umbral.
    - lanzar_train.py parchea openwakeword/train.py para torch ≥ 2.9 y torchaudio ≥ 2.9
    (sin torchcodec, exportador ONNX clásico) y evita la conversión forzada a TFLite.
    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
2026-10-09 Agregar el diseño 3D paramétrico en OpenSCAD (cad/)
    Esfera en 14 gajos y 6 círculos con junta de bayoneta y tapa de carga,
    base motriz (plantilla 1:1 de la plataforma, soportes de motor, charola
    de LiPo con lastre, soportes inclinados de ball transfer, panel de
    carga), poste con portaimanes y cabeza con plato, ojo y bocina. Todas
    las medidas en cad/parametros.scad; exportar.sh genera STL, plantilla y
    renders. Nueva página wiki/Diseno-3D.md y enlaces desde las partes 2, 5 y 6.
    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
    [base.scad, base_charola.stl, base_panel_carga.stl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]
2026-10-09 Ajustar la cotización al hardware confirmado: Uno, Pi 3, sin cámara
    La cámara OV5647 pasa a compra segura (Arducam con cable 15 → 22 para la
    Zero 2 W). La Pi 3 pide 5.1 V 2.5 A y un LM2596 da ~2 A reales, así que la
    Pi se alimenta con un XL4015 de 5 A y el LM2596 queda solo para el servo.
    Pendientes ya no tiene modelos por confirmar.
    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
2026-10-09 Ajustar el proyecto a una Raspberry Pi 3 y un Arduino Uno
    - Voz: Whisper `base` int8 con 3 hilos por defecto (small no cabe en 1 GB) y
    transcripción en la nube opcional (BB8_STT=nube, API compatible con OpenAI;
    Groq por defecto, se activa sola con BB8_STT_API_KEY).
    - Instalador de la Pi: exige el OS de 64 bits (ruedas aarch64 de faster-whisper
    y onnxruntime), activa zram y gpu_mem=16 con menos de 2 GB de RAM.
    - systemd: el servicio de movimiento con prioridad y protegido del OOM; la voz
    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
2026-10-09 CI: compilar solo para el Arduino Uno
    Erick confirmó que la placa es un Uno; se quita la matriz con el Nano.
    Claude-Session: https://claude.ai/code/session_017RAyfoahemdKWgkan8zXk2
2026-10-16 Port robot software to Go: bb8-body, bb8-head, secure link, config, agent
    - bb8-body (Pi 3): one process for serial, motion, floor plan, MCP,
    local API, config web UI (SSE, rev conflicts), OpenRouter agent and
    connectors (weather, calendar). ~11 MB RSS vs ~100 MB in Python.
    - bb8-head (Zero W, armv6): dials the body over mutual TLS 1.3
    (Ed25519, private CA via `bb8-body pair`); no open ports. Real
    backends: rpicam, NeoPixel over SPI (GPIO10), Go beeps + aplay,
    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
2026-10-17 bb8-body survives an Arduino that is late, absent or resets
    - serial.Resilient: lazy connect, back-off, reopen on a broken link; Open polls
    "I" for up to 10 s (opening the tty resets the Uno, boot takes 2–4 s).
    - motion: ArduinoUp hook (reset encoder baseline, head 0, map uncertain on
    restart), orders answer arduino_unavailable, one log line per outage,
    get_pose reports arduino_connected.
    - Tested on the real Pi by unbinding/binding the USB device.
    - Architecture: document the run-time path voice → head → body → agent →
    tools → Arduino; MCP is the external door.
    Claude-Session: https://claude.ai/code/session_017T2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
2026-10-20 Voice on the real robot: Wyoming STT/TTS, live /voice page, follow-ups
    Head
    - Eye helper uses DMA 13: DMA 10 is I2S capture on the Zero and killed arecord.
    - Eye breathes amber until the body link is up (and when it drops); the body
    replays the last eye command on reconnect.
    - Speech through a Wyoming TTS server (Piper) when BB8_TTS_WYOMING is set,
    espeak-ng as fallback.
    - Mic VAD tracks the noise floor (min of the last 2 s), so more gain or a
    steady noise no longer keeps an utterance open.
    - A sound-only beep gives the mic back after 120 ms instead of 400 ms.
    Body
    - agent: max_tokens cap (OpenRouter reserved the model maximum), prompt
    caching with the clock after the cache mark, a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
2026-10-21 Head: printable antennas with a steel wire core
    Short antenna (9 x 28 mm) and long antenna (5 x 90 mm on a 10 mm base),
    printed standing with a peg that goes into the existing holes in the top.
    A 1.5 mm steel wire through the center goes through the top and is bent
    inside, so the long one does not snap.
    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
2026-10-21 CAD: measured JGB37 motors (22 mm gearbox, 30 mm motor + encoder)
    The motors are 20 mm shorter than the datasheet value. The wheels stay at
    94 mm with a 44 mm gap between the motors: closer in, the axle drops and
    the LiPo would hit the shell. Only the motor supports and the platform
    holes change; the plates, template and Blender model are regenerated.
    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
2026-10-21 Agent: web search, remote MCP servers and a broader persona
    - web_search: OpenRouter web plugin with agent.api_key, returns answer + sources.
    - mcpclient connector: up to 3 remote MCP servers (streamable HTTP, bearer
    token); their tools appear as <name>_<tool> and are KnownOnly by default.
    - weather and web start enabled; connectors apply in goroutines so a slow
    server never blocks boot. mcpserver subscribes before its first sync
    (the async apply raced it and the MCP list missed the tools).
    - Persona: answer general questions, web_search for current facts, up to
    five sentences when asked to explain.
    Claude-Session: https://clau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
2026-10-21 Navigation: navigate_to with JEV as System 1, head ToF scan and safer forward moves
    - navigate: a step loop toward a room or furniture. Each step builds a state
    (plan waypoint, forward ToF, last scan, last results) and JEV picks one
    action as a typed choice; below navigation.min_confidence or on an error
    the local rules decide. Arriving is checked in code. Every action goes
    through motion.Service. Steps are published as nav events.
    - floorplan.Waypoint: next hop (target or first open door), and an error
    that lists the valid names.
    - motion: forward moves center the head first (the ToF is on it); without
    a reading they are cut to motion.blind_max_m; obstacle memory brakes at
    25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
2026-10-22 Config page: friendly connector cards
    One card per connector with a plain status line and the fix (Set city, Add
    key), example phrases, guided Google setup and service presets for MCP
    (Zapier, Composio, Home Assistant). Weather shows the city it matched.
    Status now carries title, description and registered tools; fields can be
    marked Advanced. Section index at the top.
    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
2026-10-22 Config page: redesign with pages, setup checklist and connect dialogs
    Sidebar pages (Overview, Brain, Home, Voice & eye, Services, Driving,
    Calibration, Activity) in the /control look. Overview lists what is
    missing. Sliders, switches and plain labels; technical settings folded.
    Apps connect through a dialog that saves only on Connect, tests the
    connection and reports the result; a failed new app is removed on Cancel.
    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
2026-10-22 Head mic: 200 Hz high-pass before the VAD, and a log line per utterance
    A minisplit put 95 % of the room noise under 200 Hz (RMS 413 vs ~115 without
    it). The VAD measured the full band, so its threshold (3.2 x noise) rose to
    ~1300 and the voice (100-650) never passed: phrases came in as 1 s of rumble
    and Whisper made up text. A 4th-order Butterworth high-pass at 200 Hz cuts that
    noise to ~103 on the same recording; on the robot the voice now measures
    365-940 over a 330-470 threshold. Each utterance logs voice, noise and threshold.
    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
2026-10-22 Head mic: the high-pass corner follows the room's noise
    While nobody speaks the head keeps the noise spectrum (512-point FFT on one
    quiet frame in four) and every ~4 s of quiet picks the corner (80-300 Hz) with
    the best expected voice-to-noise ratio against a long-term speech spectrum. It
    changes only between utterances and for a gain over 0.3 dB, carrying the noise
    estimate over. On the real minisplit recording it picks 300 Hz (noise 59 vs 103
    at a fixed 200 Hz); on the robot it moved 200 → 80 Hz when the rumble stopped
    and back to 200 when it came back.
    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
2026-10-23 Blender: the charging plate replaces the cradle (centre, 4 ramp quarters, emitter box, 24 V adapter)
    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
2026-10-23 Charging plate: grip ribs on the ramp; anti-slip sheet underneath and Plasti Dip on the shopping list
    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
2026-10-24 Base parts review before printing: 5 mm wall clearance for the tray and coil, motor bracket clipped at the platform, looser nut traps, 5.5 mm MDF, PVC post
    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
2026-10-30 Phase 1 after the first print: tray tabs that survive the LiPo pocket, fixes for the printed parts, screw kit, MDF base guide
    - base.scad: the LiPo pocket no longer cuts the tray's hanging tabs; tabs get a 45 deg gusset
    and a nut channel from below. base_charola.stl regenerated.
    - Phase 1 README: how to fix the already printed parts (brackets for the tray, drilling the
    left motor bracket and the front caster holder, servo cable through the side window) and
    the screw allocation from a 1230-piece M2-M5 kit.
    - Parte 2 rewritten for the MDF platform and printed parts; links to the 3D assembly guide.
    - Materiales: one screw kit instead of loose screws; LiPo is the soft case 138 x 43 x 32 mm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
